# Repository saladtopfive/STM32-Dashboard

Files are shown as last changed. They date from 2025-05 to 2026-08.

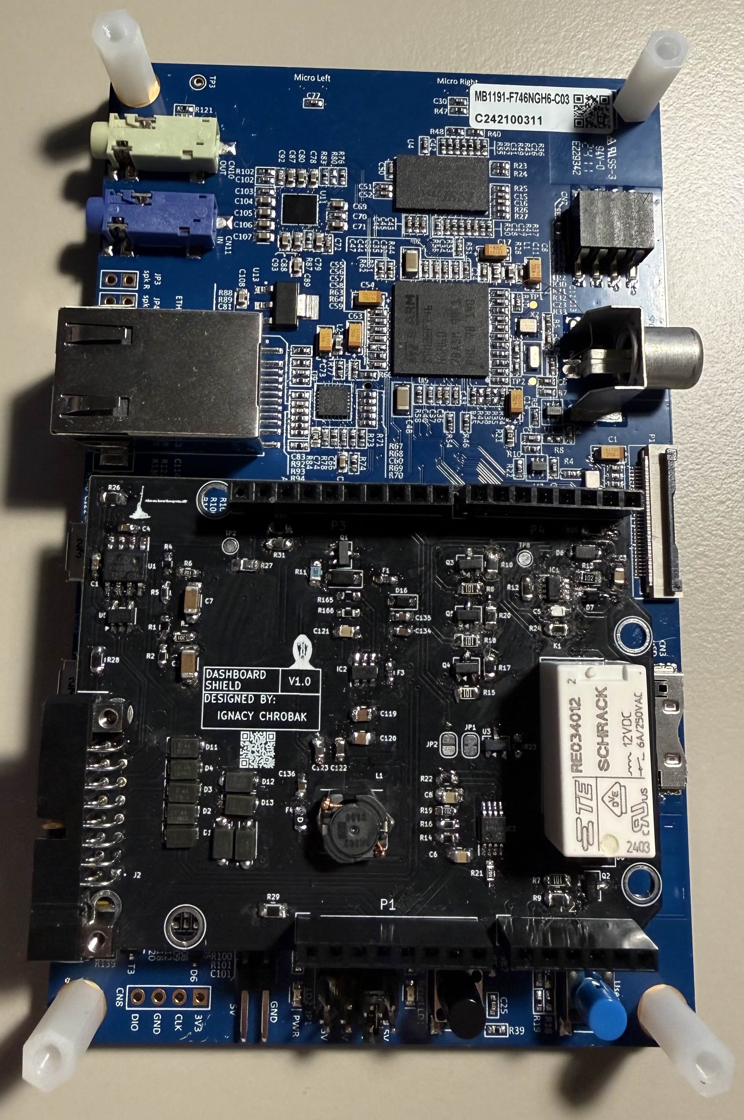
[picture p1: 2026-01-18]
readme-img/shield-stm-irl-assembly.jpg

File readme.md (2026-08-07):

# 🚘 STM32 Go-Kart Dashboard  



> [!IMPORTANT]  
> **Work suspended** — Development suspended as of **07.08.2026**  
> This repository is part of my **Engineering Thesis Project** for the completion of my undergraduate studies.  

## Overview  

This project constitutes the practical component of my **engineering thesis**, focusing on the design and implementation of a **real-time dashboard system** for an electric go-kart.  

The system is developed on the **STM32F746G-DISCO microcontroller** with a touchscreen display using **TouchGFX**, and is intended to collect, process, and visualize telemetry data from multiple hardware sensors.  

The dashboard serves as a **human–machine interface (HMI)**, enabling the driver to monitor essential parameters of the vehicle in real time. These include, but are not limited to:  

## Preview

| Main Screen | Error Table |
|---|---|
| dashboard-preview-screen1 | dashboard-preview-screen2 |

| Temperature Table | Battery Table |
|---|---|
| dashboard-preview-screen3 | dashboard-preview-screen4 |

## Monitored Metrics  

| ***Metric*** | ***Description*** |
|---|---|
| **Vehicle Speed** | Real-time speed display. |
| **Throttle / Brake** | Input level visualization. |
| **Battery** | Voltage and temperature monitoring. |
| **Motor Temperature** | Prevents overheating and ensures reliability. |
| **G-Forces** | Lateral and vertical forces in real time. |
| **BMS Data (External)** | Additional telemetry provided by an external Battery Management System (BMS), developed as a separate thesis project. This work only focuses on visualization of the received data. |
| **HOTLAP Button** | Initiates a lap timer (stopwatch) in the dashboard, showing minutes, seconds, and centiseconds. Useful for tracking lap times during testing or racing sessions. |
| **Future Extensions** | Additional sensor integrations planned. |

The objective of this work is to provide a **robust, responsive, and intuitive interface** that supports safe and efficient operation of the electric go-kart.  

## Hardware

As part of the project, a custom **Arduino Shield** is being developed to handle all sensor inputs, signal routing, and electrical interfacing between the go-kart hardware and the STM32 dashboard.  

### KiCad Schematic Preview

kicad_schematic

### KiCad 3D Model Preview

3d-render

### IRL pictures

| STM32 - dashboard | Shield |
|---|---|
| dash_realizacja_irl | shield_realizacja_irl |

## Development Notes  

The project was initially developed without version control, with the focus placed on prototyping and interface design. 

As the implementation approaches the stage of **hardware integration**, this repository has been introduced to serve as a platform for:  

- Source code management and tracking.  
- Documentation of development progress. 
- Collaboration and versioning.  

## Roadmap  

| ***Status*** | ***Task*** |
|---|---|
|  **Done** | Acquisition of the go-kart frame. |
|  **Done** | Development of the UI prototype. |
|  **Ongoing** | Live sensor data implementation. |
|  **Ongoing** | Development of an export data feature. |
|  **Ongoing** | Implementation of battery management visualization. |
|  **Planned** | Integration of BLDC motor control. |

## License
This project is licensed under the MIT permissive license.

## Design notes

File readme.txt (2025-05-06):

# STM32 Go-Kart Dashboard

A TouchGFX-based digital dashboard for a go-kart, simulating speed, throttle, G-forces, and indicators — with plans to integrate real-world sensor inputs on STM32 hardware.

---

## Overview

This project provides a real-time dashboard UI designed for STM32 microcontrollers with a touchscreen display. It visually represents speed, throttle level, G-forces (as a moving ball), and turn signals. The UI is developed using TouchGFX and STM32 HAL, currently operated through simulated hardware inputs for development on PC.

---

## Features

- **Speed display** with incremental control
- **Throttle bar** that increases while held and decays naturally
- **G-force ball** showing lateral and vertical force within a circular gauge
- **Turn indicator lights** with fade-in/fade-out flash behavior
- Dual input support: **on-screen buttons** and **hardware keys** (PC)
- Real-time **tick-based animation handling**

---

## Sensor Integration (Upcoming)

Currently, this dashboard is controlled via PC keyboard to simulate hardware inputs. The next development stage involves replacing these with real sensor data:

- Steering wheel input 
- Throttle 
- G-force 
- Turn signals 

---

## Why So Late?

The project was added to version control at a late stage because GitHub integration wasn’t deemed necessary earlier. It’s only now — approaching hardware implementation — that source tracking and documentation became essential for continued development and collaboration.

---

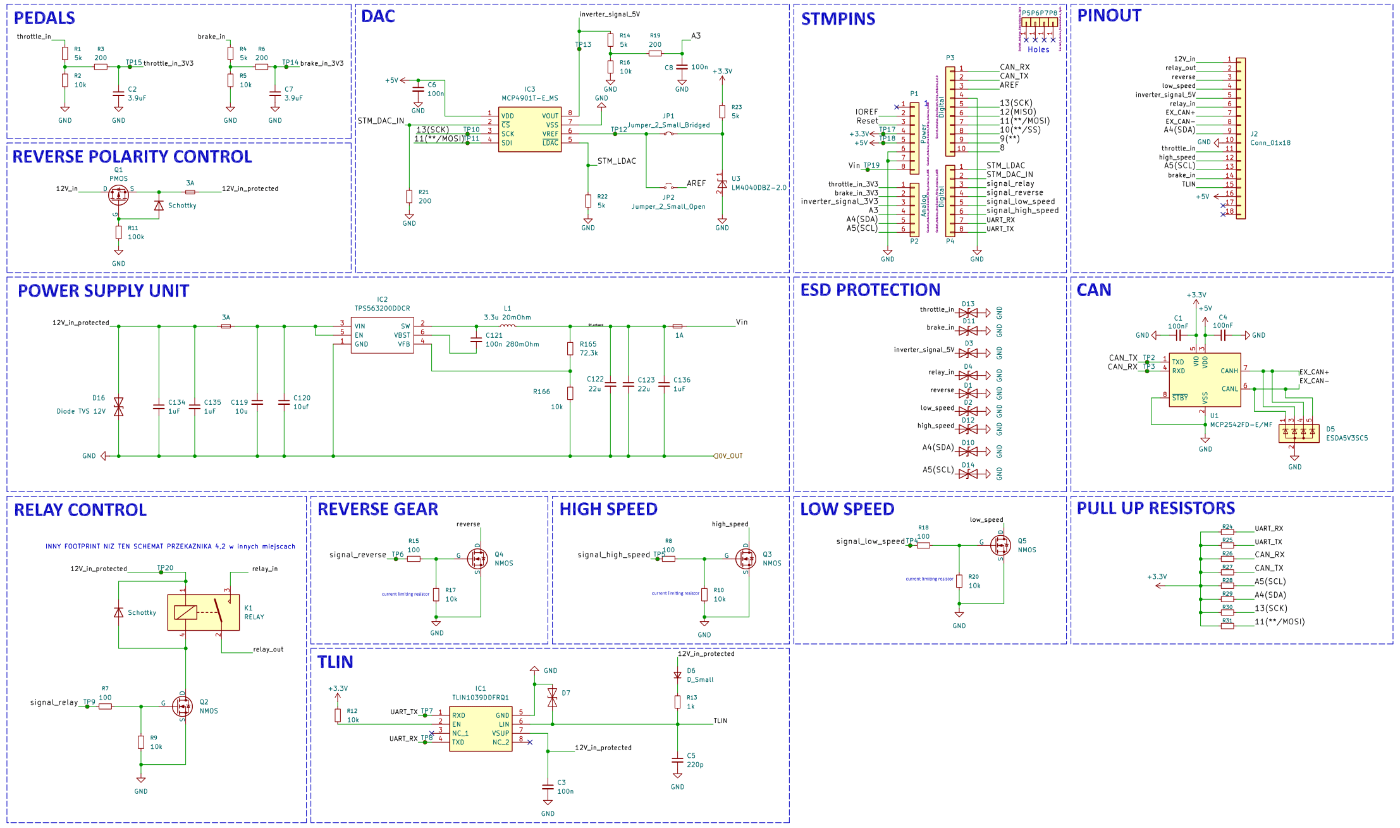
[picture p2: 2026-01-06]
readme-img/kicad_schematic.png

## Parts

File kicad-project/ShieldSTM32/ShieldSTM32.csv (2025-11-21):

Reference | Qty | Value | DNP | Exclude from BOM | Exclude from Board | Footprint | Datasheet
C1,C4 | 2 | 100nF |  |  |  | Capacitor_SMD:C_0603_1608Metric_Pad1.08x0.95mm_HandSolder | ~
C2,C7 | 2 | 3.9uF |  |  |  | Capacitor_SMD:C_1206_3216Metric_Pad1.33x1.80mm_HandSolder | https://www.mouser.pl/ProductDetail/KEMET/C1206C395M3PACTU
C3,C6,C8 | 3 | 100n |  |  |  | Capacitor_SMD:C_0805_2012Metric_Pad1.18x1.45mm_HandSolder
C5 | 1 | 220p |  |  |  | Capacitor_SMD:C_0805_2012Metric_Pad1.18x1.45mm_HandSolder
C119 | 1 | 10u |  |  |  | Capacitor_SMD:C_0805_2012Metric_Pad1.18x1.45mm_HandSolder | https://www.mouser.pl/ProductDetail/TDK/C2012X5R1V106K085AC?qs=6JAMGB%252BEdky%252BlYMcTLhFyA%3D%3D
C120 | 1 | 10uf |  |  |  | Capacitor_SMD:C_0805_2012Metric_Pad1.18x1.45mm_HandSolder | https://www.mouser.pl/ProductDetail/TDK/C2012X5R1V106K085AC?qs=6JAMGB%252BEdky%252BlYMcTLhFyA%3D%3D
C121 | 1 | 100n 280mOhm |  |  |  | Capacitor_SMD:C_0805_2012Metric_Pad1.18x1.45mm_HandSolder | https://www.mouser.pl/ProductDetail/KYOCERA-AVX/08053C104KAT2A?qs=EihRZLdKnF2GcTBzDkE%2FiQ%3D%3D
C122,C123 | 2 | 22u |  |  |  | Capacitor_SMD:C_0603_1608Metric_Pad1.08x0.95mm_HandSolder | https://www.mouser.pl/ProductDetail/TDK/C1608X5R1A226M080AC?qs=dfay7wIA1uED3Fb1o4f9Dg%3D%3D
C134,C135,C136 | 3 | 1uF |  |  |  | Capacitor_SMD:C_0603_1608Metric_Pad1.08x0.95mm_HandSolder | https://www.mouser.pl/ProductDetail/TAIYO-YUDEN/EMK107B7105MA8T
D1,D2,D3,D4,D10,D11,D12,D13,D14 | 9 | 6V |  |  |  | Diode_SMD:D_SOD-123F | https://www.mouser.pl/ProductDetail/Littelfuse/SZSMF6L6.0AT3G?qs=NeOn4crkEuuL8kPOknXE%2Fw%3D%3D
D5 | 1 | ESDA5V3SC5 |  |  |  | Package_TO_SOT_SMD:SOT-23-5 | https://www.st.com/resource/en/datasheet/esda5v3sc6.pdf
D6 | 1 | D_Small |  |  |  | footprint:SODFL3618X100N | https://www.mouser.pl/ProductDetail/Comchip-Technology/ACGRTS4002-HF?qs=vLWxofP3U2xDO8WfdetXSg%3D%3D
D7 | 1 | ESD131-B1-W0201 |  |  |  | footprint:SOD2613X100N | https://www.mouser.pl/ProductDetail/Texas-Instruments/ESD1LIN24DYFR?qs=rQFj71Wb1eUZk7C7kdpseg%3D%3D
D8,D9 | 2 | Schottky |  |  |  | Diode_SMD:D_SOD-123 | https://www.mouser.pl/ProductDetail/Taiwan-Semiconductor/SD103BWH-RHG?qs=jcD%2FCkGBYeNNhWZ4uMM1kw%3D%3D
D16 | 1 | Diode TVS 12V |  |  |  | Diode_SMD:D_SOD-323_HandSoldering | https://www.mouser.pl/ProductDetail/Diodes-Incorporated/SD12C-7?qs=EBDBlbfErPxugjAb5VaoMA%3D%3D
F1,F3 | 2 | 3A |  |  |  | Fuse:Fuse_0603_1608Metric_Pad1.05x0.95mm_HandSolder | https://www.mouser.pl/ProductDetail/Bourns/SF-0603FP300F-2?qs=55YtniHzbhAz28pQ%252B5v2Gg%3D%3D
F4 | 1 | 1A |  |  |  | Fuse:Fuse_0603_1608Metric_Pad1.05x0.95mm_HandSolder | https://www.mouser.pl/ProductDetail/Bourns/SF-0603F100-2
IC1 | 1 | TLIN1039DDFRQ1 |  |  |  | SOT65P280X110-8N | https://www.ti.com/product/TLIN1039-Q1
IC2 | 1 | TPS563200DDCR |  |  |  | footprint:TPS563200DDCR | http://www.ti.com/lit/gpn/TPS563200
IC3 | 1 | MCP4901T-E_MS |  |  |  | SOP65P490X110-8N | https://datasheet.datasheetarchive.com/originals/dk/DKDS41/DSANUWW0026513.pdf
J2 | 1 | Conn_01x18 |  |  |  | footprint:M80-54016YY | https://www.mouser.pl/ProductDetail/Harwin/M80-5401642?qs=wuXwK9wHm9sx2x5KnF4SHQ%3D%3D
JP1 | 1 | Jumper_2_Small_Bridged |  |  |  | Jumper:SolderJumper-2_P1.3mm_Bridged_RoundedPad1.0x1.5mm | ~
JP2 | 1 | Jumper_2_Small_Open |  |  |  | Jumper:SolderJumper-2_P1.3mm_Open_RoundedPad1.0x1.5mm | ~
K1 | 1 | RELAY |  |  |  | footprint:RE034012 | https://www.mouser.pl/ProductDetail/TE-Connectivity/RE034012?qs=9VCAlN3zIjnPkD8RaiRpIA%3D%3D
L1 | 1 | 3.3u 20mOhm |  |  |  | footprint:CLF7045__ | https://www.mouser.pl/ProductDetail/TDK/CLF7045NIT-3R3N-D?qs=P8zzrVhehaveWwbrqo7%252Bdg%3D%3D
P1 | 1 | Power |  |  |  | Socket_Arduino_Uno:Socket_Strip_Arduino_1x08
P2 | 1 | Analog |  |  |  | Socket_Arduino_Uno:Socket_Strip_Arduino_1x06
P3 | 1 | Digital |  |  |  | Socket_Arduino_Uno:Socket_Strip_Arduino_1x10
P4 | 1 | Digital |  |  |  | Socket_Arduino_Uno:Socket_Strip_Arduino_1x08
P5,P6,P7,P8 | 4 | CONN_01X01 |  |  |  | Socket_Arduino_Uno:Arduino_1pin
Q1 | 1 | PMOS |  |  |  | Package_TO_SOT_SMD:SOT-23-3 | https://www.mouser.pl/ProductDetail/onsemi/NTR4502PT1G?qs=ZXBb0xZ9WeB%2Fr7xn7qkqLg%3D%3D
Q2,Q3,Q4,Q5 | 4 | NMOS |  |  |  | Package_TO_SOT_SMD:SOT-23-3 | https://www.mouser.pl/ProductDetail/onsemi/NTR4003NT3G?qs=CBDP9nzV7kn2N6bgfQxrAA%3D%3D
R1,R4,R14,R22,R23 | 5 | 5k |  |  |  | Resistor_SMD:R_0603_1608Metric_Pad0.98x0.95mm_HandSolder | ~
R2,R5,R16 | 3 | 10k |  |  |  | Resistor_SMD:R_0603_1608Metric_Pad0.98x0.95mm_HandSolder | ~
R3,R6,R19,R21 | 4 | 200 |  |  |  | Resistor_SMD:R_0603_1608Metric_Pad0.98x0.95mm_HandSolder | ~
R7,R8,R15,R18 | 4 | 100 |  |  |  | Resistor_SMD:R_0805_2012Metric_Pad1.20x1.40mm_HandSolder | ~
R9,R10,R12,R17,R20,R24,R25,R26,R27,R28,R29,R30,R31 | 13 | 10k |  |  |  | Resistor_SMD:R_0805_2012Metric_Pad1.20x1.40mm_HandSolder | ~
R11 | 1 | 100k |  |  |  | Resistor_SMD:R_0805_2012Metric_Pad1.20x1.40mm_HandSolder | ~
R13 | 1 | 1k |  |  |  | Resistor_SMD:R_0805_2012Metric_Pad1.20x1.40mm_HandSolder | ~
R165 | 1 | 56.2k 50mW |  |  |  | Resistor_SMD:R_0603_1608Metric_Pad0.98x0.95mm_HandSolder | https://www.mouser.pl/ProductDetail/YAGEO/RC0201FR-0756K2L?qs=Q4gDqC5t5%2FD3%2Fkjmz2Nr%2Fw%3D%3D
R166 | 1 | 10k 50mW |  |  |  | Resistor_SMD:R_0603_1608Metric_Pad0.98x0.95mm_HandSolder | ~
TP2,TP3,TP4,TP5,TP6,TP7,TP8,TP9,TP10,TP11,TP12,TP13,TP14,TP15,TP17,TP18,TP19,TP20 | 18 | TestPoint_Small |  |  |  | TestPoint:TestPoint_Pad_D1.5mm | ~
U1 | 1 | MCP2542FD-E/MF |  |  |  | footprint:SOIC127P600X175-8N | https://www.mouser.pl/ProductDetail/Microchip-Technology/MCP2542FD-E-SN?qs=qdgZG5p0FZ5pNizBl1u80Q%3D%3D
U3 | 1 | LM4040DBZ-2.0 |  |  |  | Package_TO_SOT_SMD:SOT-23 | http://www.ti.com/lit/ds/symlink/lm4040-n.pdf

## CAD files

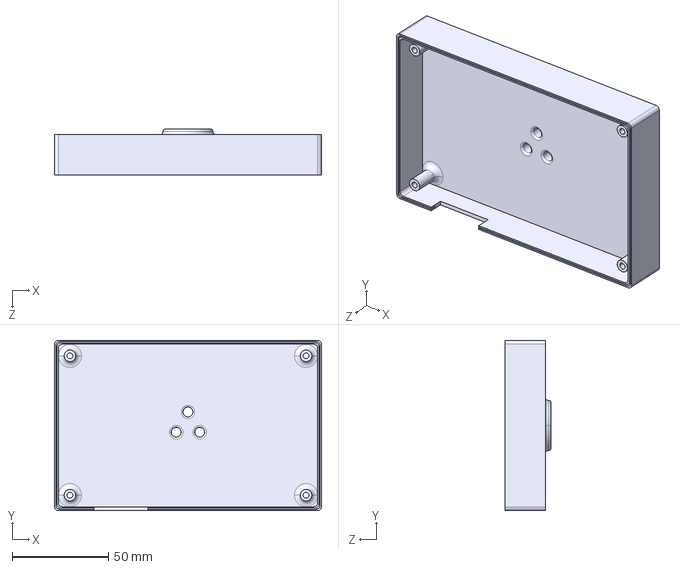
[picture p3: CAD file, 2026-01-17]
freecad-project-mounting_plate/dash_mounting-3dmodel/tyl.STEP
138.4 x 88.2 x 24.0 mm

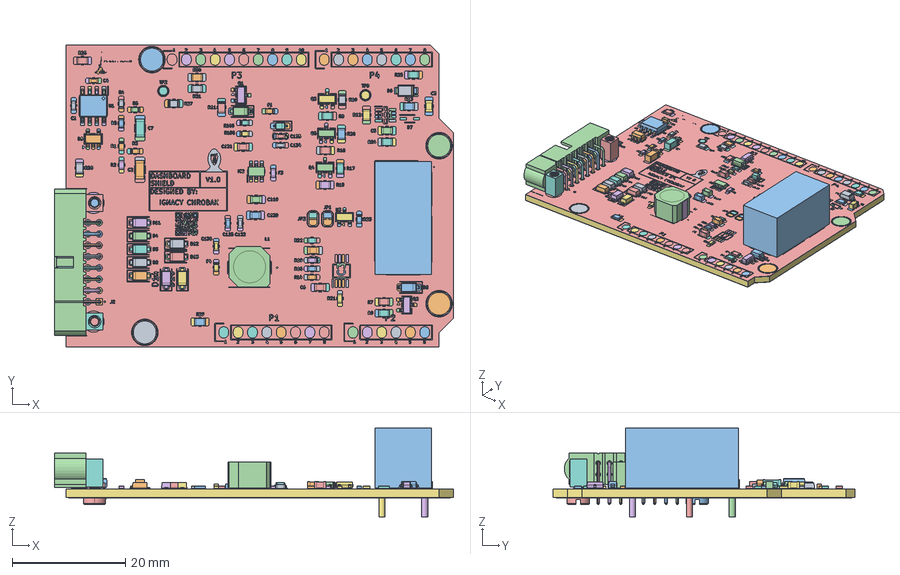
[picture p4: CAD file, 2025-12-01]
freecad-project-mounting_plate/shield-3dmodel/3dmodel.FCStd
70.6 x 53.3 x 15.7 mm
R_0805_2012Metric
C_0603_1608Metric
PinsArrayLR
PinsArrayLR001
PinsArrayLR002
PinsArrayLR003
PinsArrayLR004
PinsArrayLR005
PinsArrayLR006
PinsArrayLR007
BODY-SOT
LEAD-SOT
LEAD-SOT001
LEAD-SOT002
LEAD-SOT003
LEAD-SOT004
LEAD-SOT005
R_0805_2012Metric001
D_SOD-123
D_SOD-123F
D_SOD-123F001
Fuse_0603_1608Metric
D_SOD-323
C_0603_1608Metric001
D_SOD-123F002
C_0603_1608Metric002
R_0603_1608Metric
C_0805_2012Metric
R_0603_1608Metric001
R_0805_2012Metric002
D_SOD-123F003
PinKIdent
PinK
PinA
R_0805_2012Metric003
SOT-23-3
C_0603_1608Metric003
R_0603_1608Metric002
C_0603_1608Metric004
R_0603_1608Metric003
R_0805_2012Metric004
SOT-23-004
R_0805_2012Metric005
R_0805_2012Metric006
R_0603_1608Metric004
R_0603_1608Metric005
R_0805_2012Metric007
Fuse_0603_1608Metric001
R_0805_2012Metric008
C_0805_2012Metric001
C_0805_2012Metric002
Fuse_0603_1608Metric002
C_0805_2012Metric003
R_0805_2012Metric009
R_0805_2012Metric010
C_1206_3216Metric
R_0603_1608Metric006
C_0805_2012Metric004
R_0805_2012Metric011
R_0603_1608Metric007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

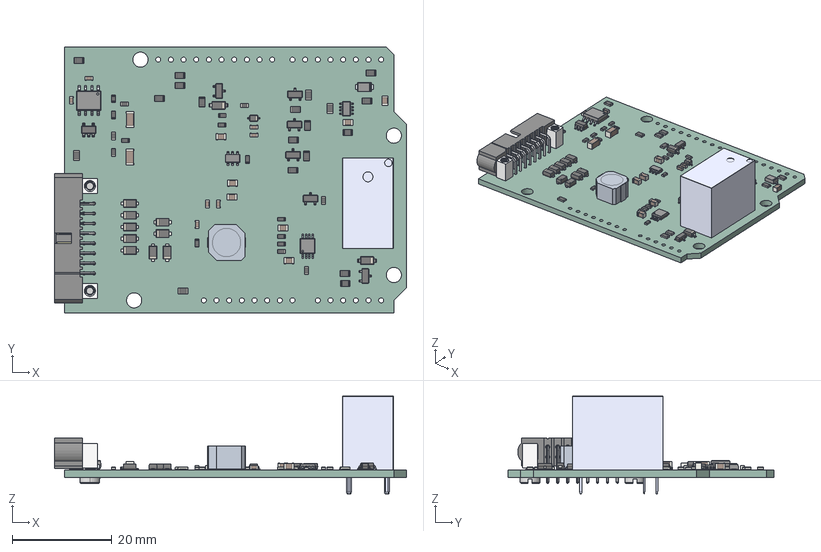
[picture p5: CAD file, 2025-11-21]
kicad-project/project/step/ShieldArduino_Semaforo.step
70.6 x 53.3 x 19.6 mm
Socket_header_Arduino_1x08 x 2
Socket_header_Arduino_1x06
Socket_header_Arduino_1x10
R_0805_2012Metric x 19
C_0603_1608Metric x 7
PinsArrayLR x 2
BODY-SOT
LEAD-SOT x 6
D_SOD-123 x 2
D_SOD-123F x 9
Fuse_0603_1608Metric x 3
D_SOD-323
R_0603_1608Metric x 14
C_0805_2012Metric x 7
PinKIdent
PinK
PinA
SOT-23-3 x 5
BODY-SO
LEAD-SO x 8
PIN1-ID
C_1206_3216Metric x 2
CLF7045NIf
CLF7045NI[q x 2
PR4-12V-450-1A
M80-2702098_SEPARATE_ROWS
M80-530XX22_SHORT_PIN x 8
M80-530XX22_LONG_PIN x 8
SOT-23-5
SOT-23
ShieldArduino_Semaforo_PCB

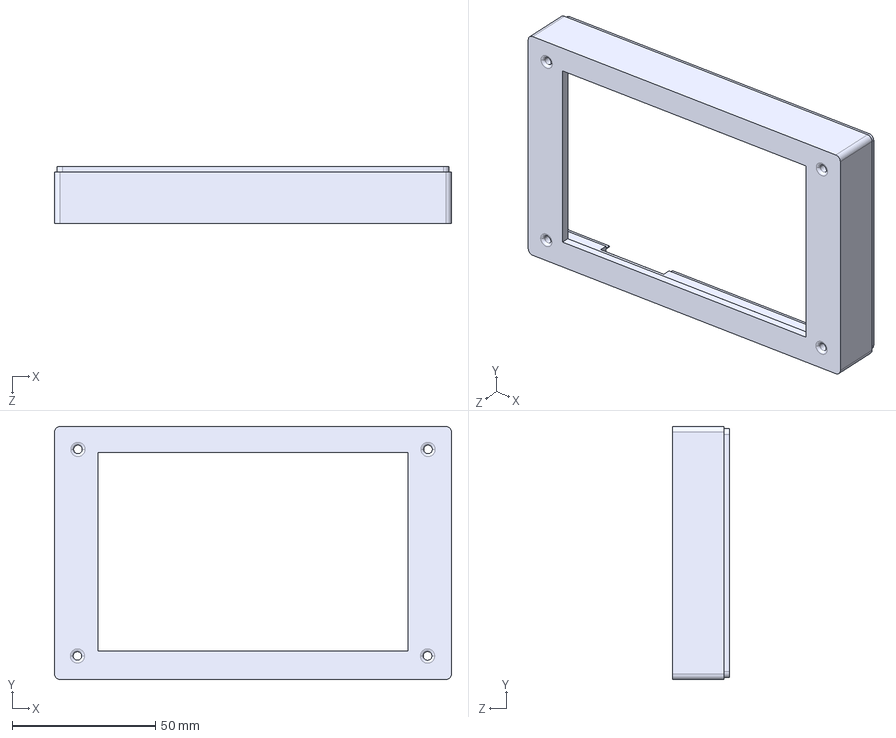
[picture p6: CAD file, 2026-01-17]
freecad-project-mounting_plate/dash_mounting-3dmodel/przod.STEP
138.4 x 88.2 x 20.0 mm

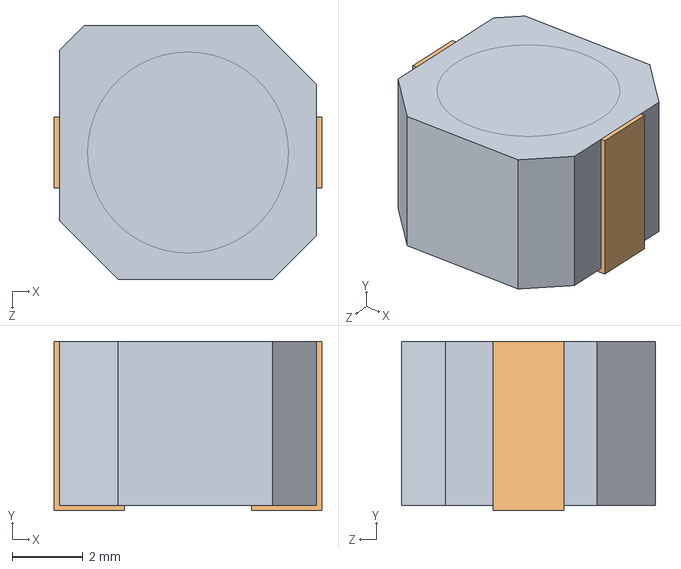
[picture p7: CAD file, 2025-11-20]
kicad-project/ShieldSTM32/include/model/CLF7045NIT-3R3N-D.stp
7.60 x 4.80 x 7.20 mm
CLF7045NI素体
CLF7045NI端子 x 2

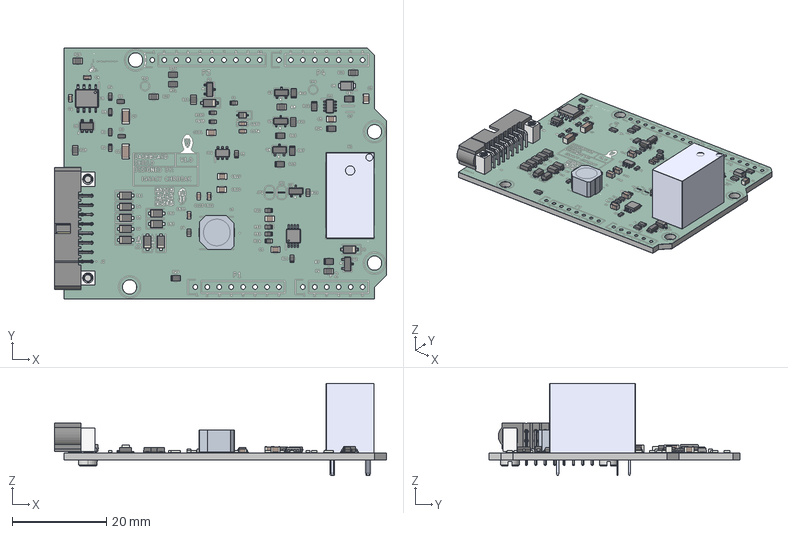
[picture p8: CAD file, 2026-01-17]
freecad-project-mounting_plate/dash_mounting-3dmodel/ShieldArduino_Semaforo.step
70.6 x 53.3 x 19.6 mm
Socket_header_Arduino_1x08 x 2
Socket_header_Arduino_1x06
Socket_header_Arduino_1x10
R_0805_2012Metric x 19
C_0603_1608Metric x 7
PinsArrayLR x 2
BODY-SOT
LEAD-SOT x 6
D_SOD-123 x 2
D_SOD-123F x 9
Fuse_0603_1608Metric x 3
D_SOD-323
R_0603_1608Metric x 14
C_0805_2012Metric x 7
PinKIdent
PinK
PinA
SOT-23-3 x 5
BODY-SO
LEAD-SO x 8
PIN1-ID
C_1206_3216Metric x 2
CLF7045NIf
CLF7045NI[q x 2
PR4-12V-450-1A
M80-2702098_SEPARATE_ROWS
M80-530XX22_SHORT_PIN x 8
M80-530XX22_LONG_PIN x 8
SOT-23-5
SOT-23
ShieldArduino_Semaforo_silkscreen
ShieldArduino_Semaforo_soldermask
ShieldArduino_Semaforo_PCB

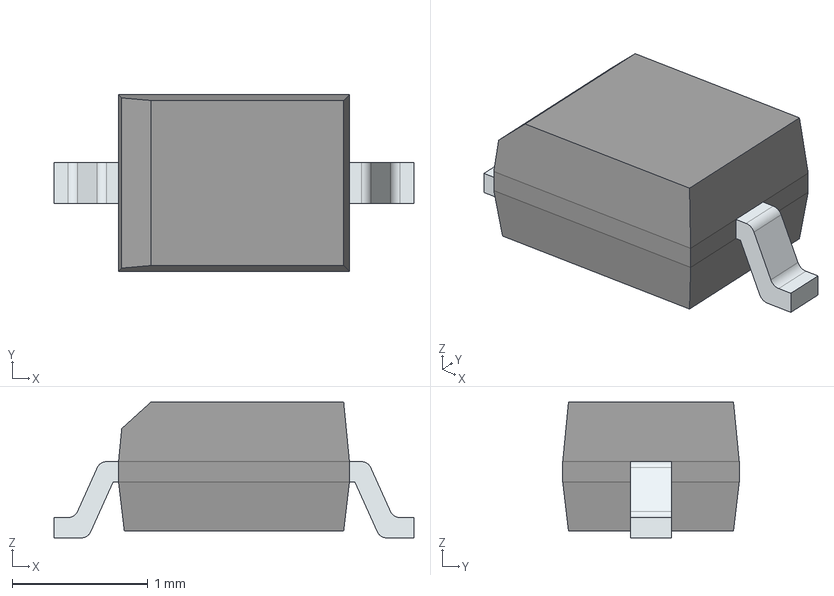
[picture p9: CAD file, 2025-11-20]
kicad-project/ShieldSTM32/include/model/ESD1LIN24DYFR.stp
2.65 x 1.30 x 1.00 mm
FilletPinL
FilletPinR

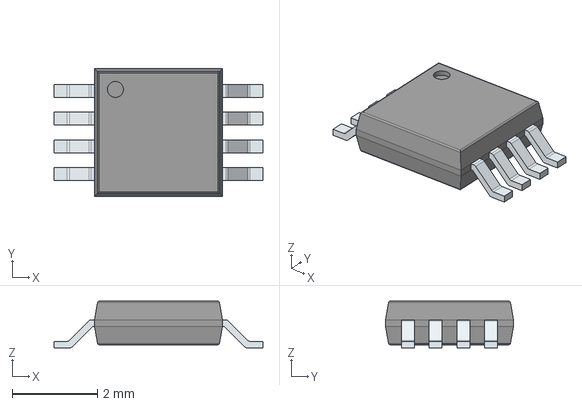
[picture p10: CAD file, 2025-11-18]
kicad-project/ShieldSTM32/include/model/MCP4901T-E_MS.stp
4.90 x 3.00 x 1.10 mm
PinsArrayLR

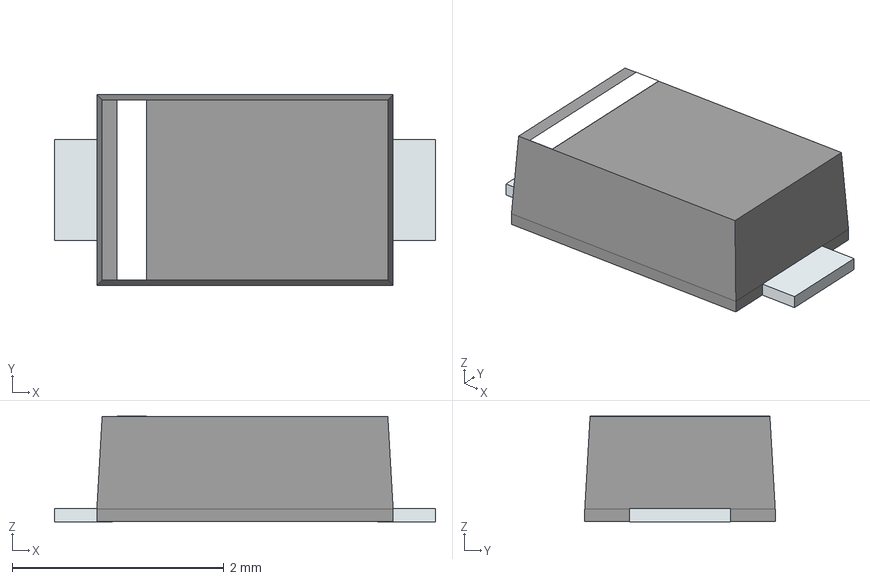
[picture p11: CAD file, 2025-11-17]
kicad-project/ShieldSTM32/include/model/ACGRTS4002-HF.stp
3.60 x 1.80 x 1.00 mm
PinKIdent
PinK
PinA

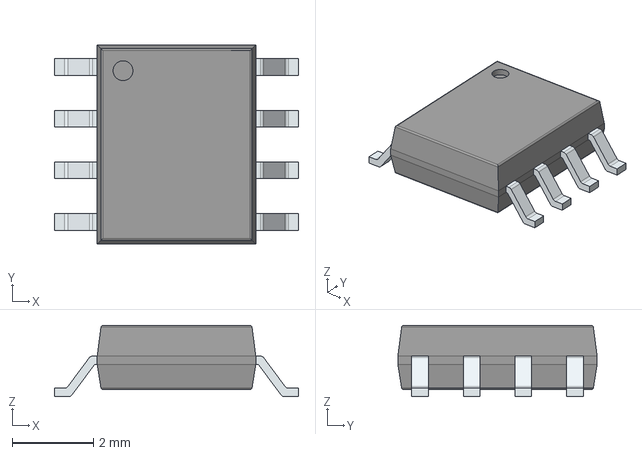
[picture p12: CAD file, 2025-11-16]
kicad-project/ShieldSTM32/include/model/MCP2542FD-E_SN.stp
6.00 x 4.90 x 1.75 mm
PinsArrayLR

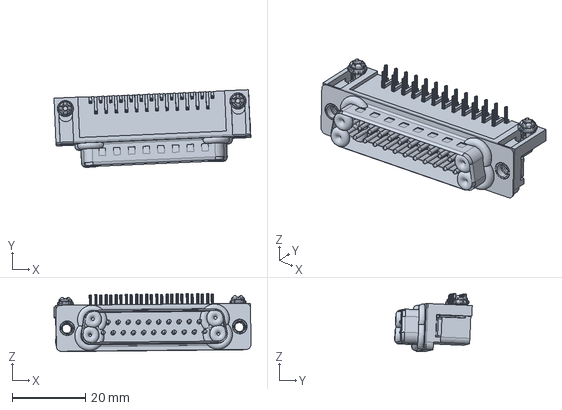
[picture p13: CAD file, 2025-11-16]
kicad-project/ShieldSTM32/include/model/L717SDB25PA4CH3R.stp
53.6 x 21.1 x 15.8 mm

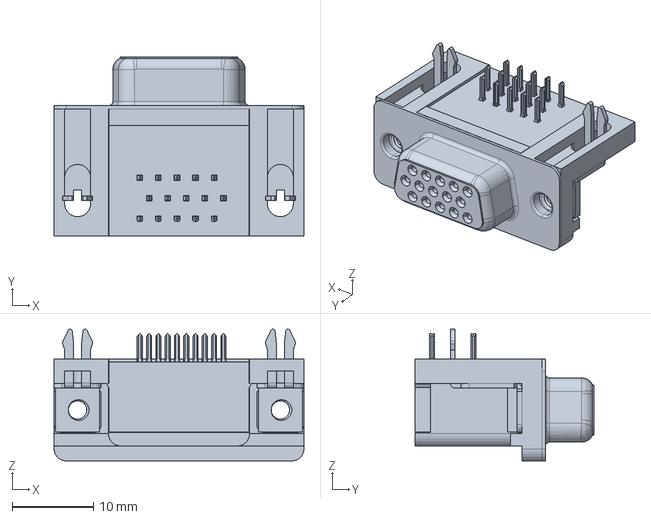
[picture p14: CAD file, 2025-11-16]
kicad-project/ShieldSTM32/include/model/L17HTHES4R1C.stp
30.8 x 22.1 x 16.2 mm

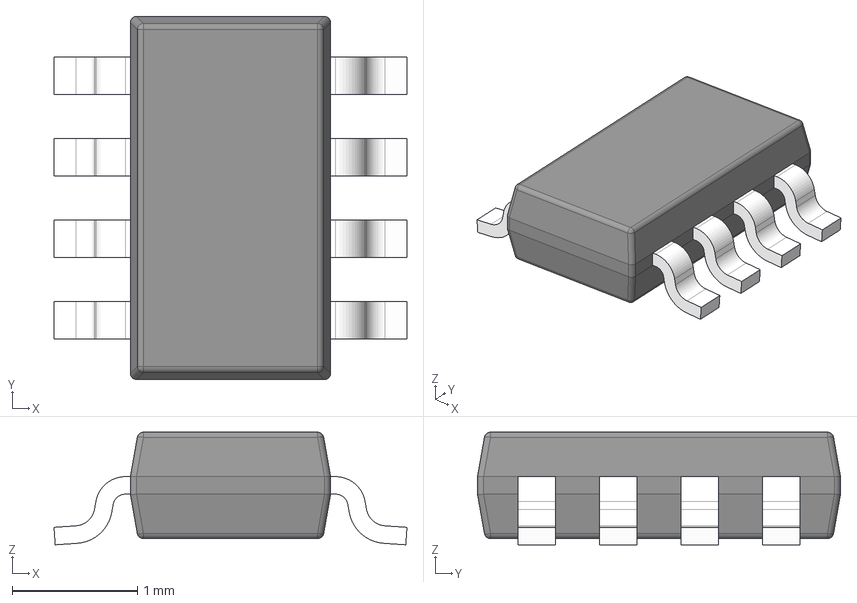
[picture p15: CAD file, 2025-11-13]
kicad-project/ShieldSTM32/include/model/TLIN1039DDFRQ1.stp
2.82 x 2.90 x 0.9 mm
BODY-SO
LEAD-SO x 8
PIN1-ID

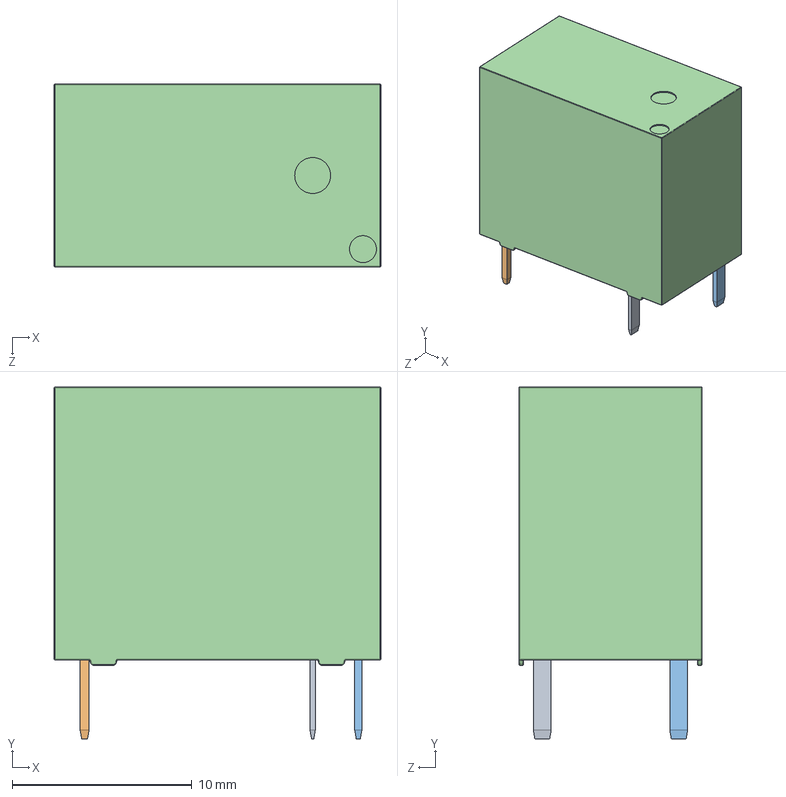
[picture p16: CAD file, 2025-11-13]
kicad-project/ShieldSTM32/include/model/PR4-12V-450-1A.stp
18.2 x 19.6 x 10.2 mm

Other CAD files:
freecad-project-mounting_plate/dash_mounting-3dmodel/dash.SLDASM
kicad-project/ShieldSTM32/include/model/M80-5001042.stp
kicad-project/ShieldSTM32/include/model/RE034012.stp
kicad-project/ShieldSTM32/include/model/M80-5401642.stp
freecad-project-mounting_plate/dash_mounting-3dmodel/przod.SLDPRT
freecad-project-mounting_plate/dash_mounting-3dmodel/tyl.SLDPRT
kicad-project/ShieldSTM32/include/model/TPS54302DDCR.stp

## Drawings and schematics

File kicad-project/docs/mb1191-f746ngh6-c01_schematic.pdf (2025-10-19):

Title: Project overview

Size:

Reference:
A4 | Sheet: | of

Revision:

Project: STM32F746G-DISCO

C 01 | MB1191

F746NGH6

Date:

Variant:

Table of contents | Legend

General comment such as function title, configuration, ...

Text to be added to silkscreen.

# STM32F746G-DISCO

MB1191

Warning text.

# Open Platform License Agreement

The Open Platform License Agreement (“Agreement”) is a binding legal contract between you ("You")

and STMicroelectronics International N.V. (“ST”), a company incorporated under the laws of the

Netherlands acting for the purpose of this Agreement through its Swiss branch 39, Chemin du

Champ des Filles, 1228 Plan-les-Ouates, Geneva, Switzerland.

By using the enclosed reference designs, schematics, PC board layouts, and documentation, in hardcopy

or CAD tool file format (collectively, the “Reference Material”), You are agreeing to be bound by

the terms and conditions of this Agreement. Do not use the Reference Material until You have read

and agreed to this Agreement terms and conditions. The use of the Reference Material automatically

implies the acceptance of the Agreement terms and conditions.

The complete Open Platform License Agreement can be found on www.st.com/opla.

U_Top
Top.SchDoc

Sheet 1: Project overview (this page)

Sheet 2: Top

Sheet 4: ST-LINK/V2-1 with support of SWD only

Sheet 5: Joystick, ACP, LEDs and Push Button

Sheet 8: Arduino UNO connectors

Sheet 10: USB OTG FS with Micro A-B connector

Sheet 7: Quad SPI Flash Memory (MICRON)

Sheet 6: Audio Codec WOLFSON and connectors

Sheet 9: SDRAM (MICRON)

Sheet 3: STM32F746NGH6 Connexion

Sheet 11: USB OTG HS PHY with Micro A-B connector

Sheet 12: Ethernet PHY with RJ45 connector

Sheet 13: External Camera connector

Sheet 14: LCD 4.3" with Capacitive Touch

Notes to generate the
board layout.

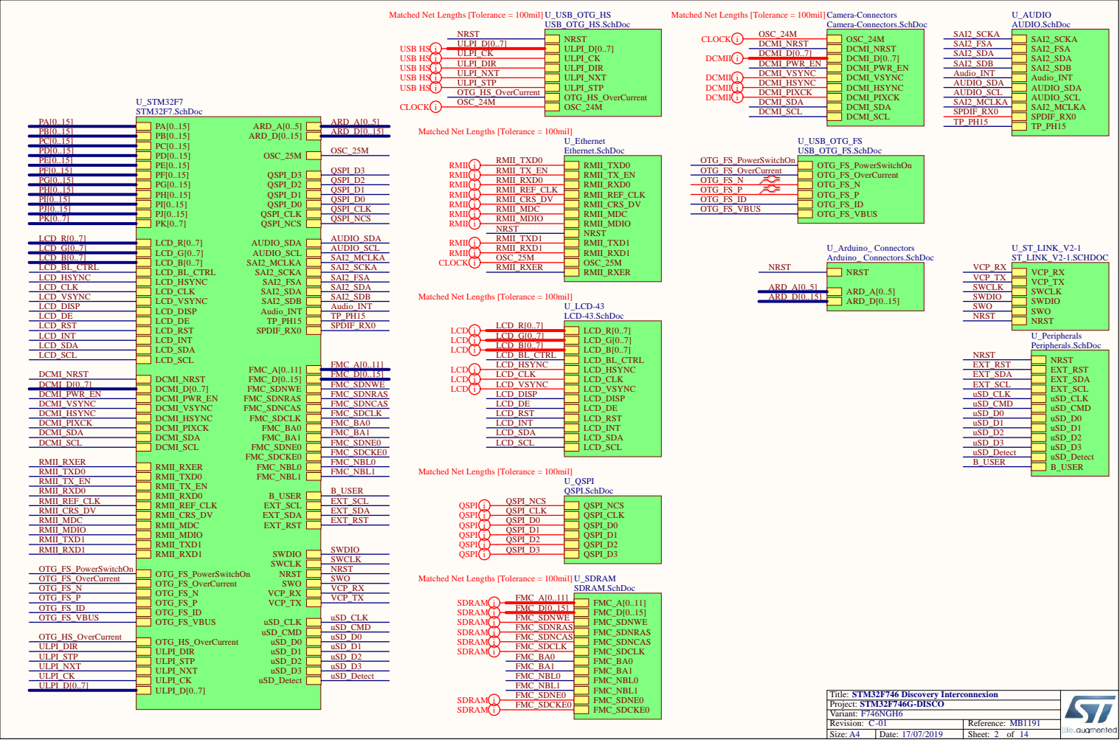
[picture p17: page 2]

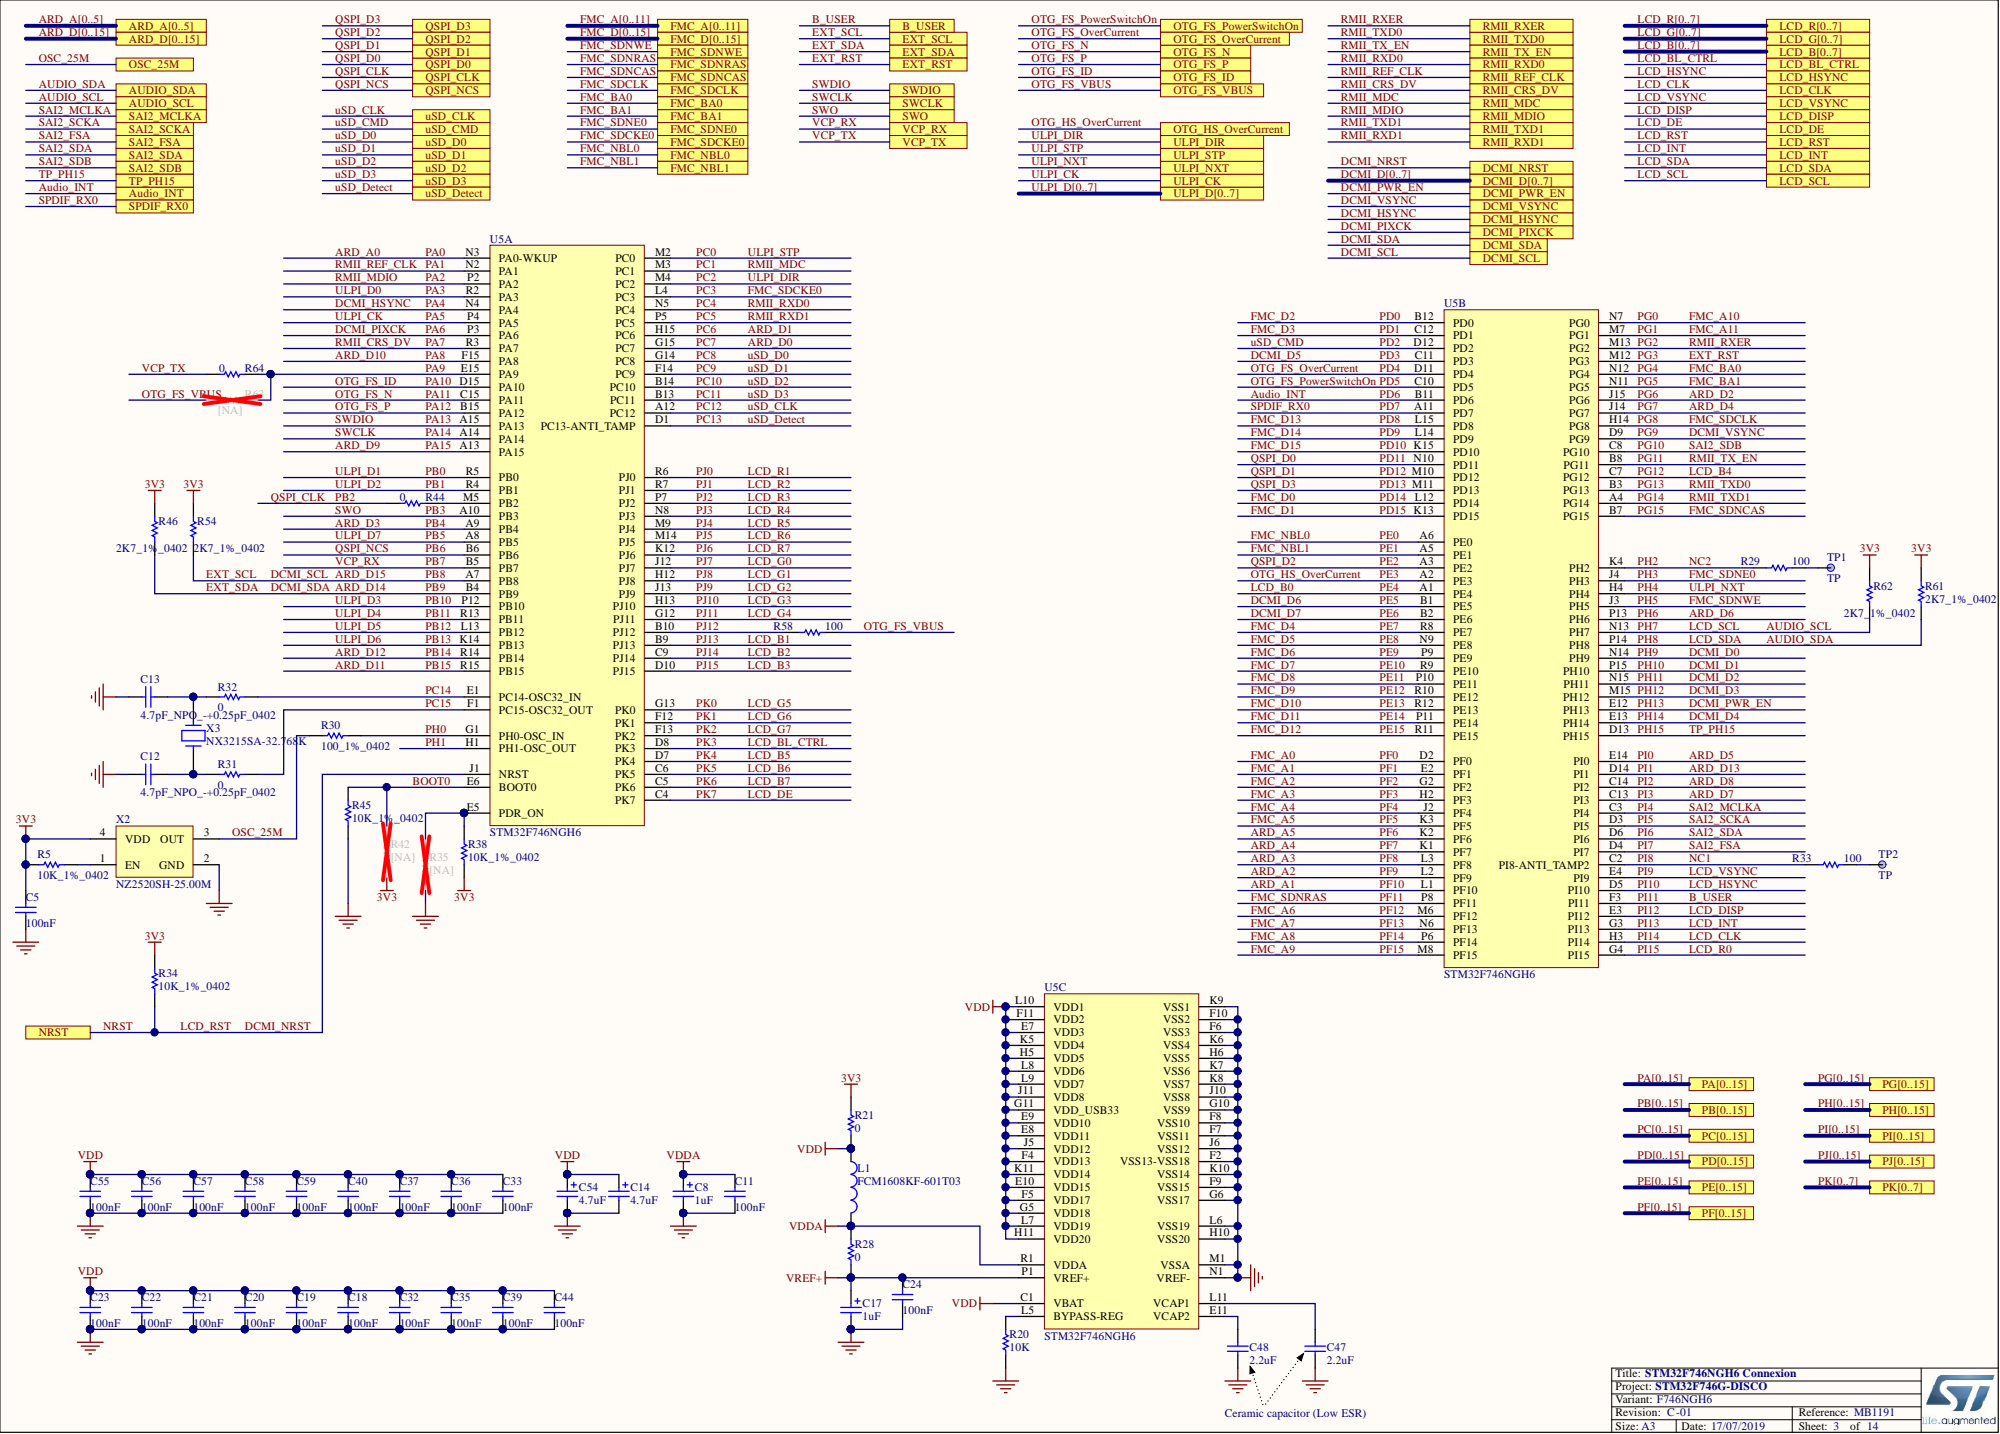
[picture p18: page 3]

VREF+ P1

Ceramic capacitor (Low ESR)

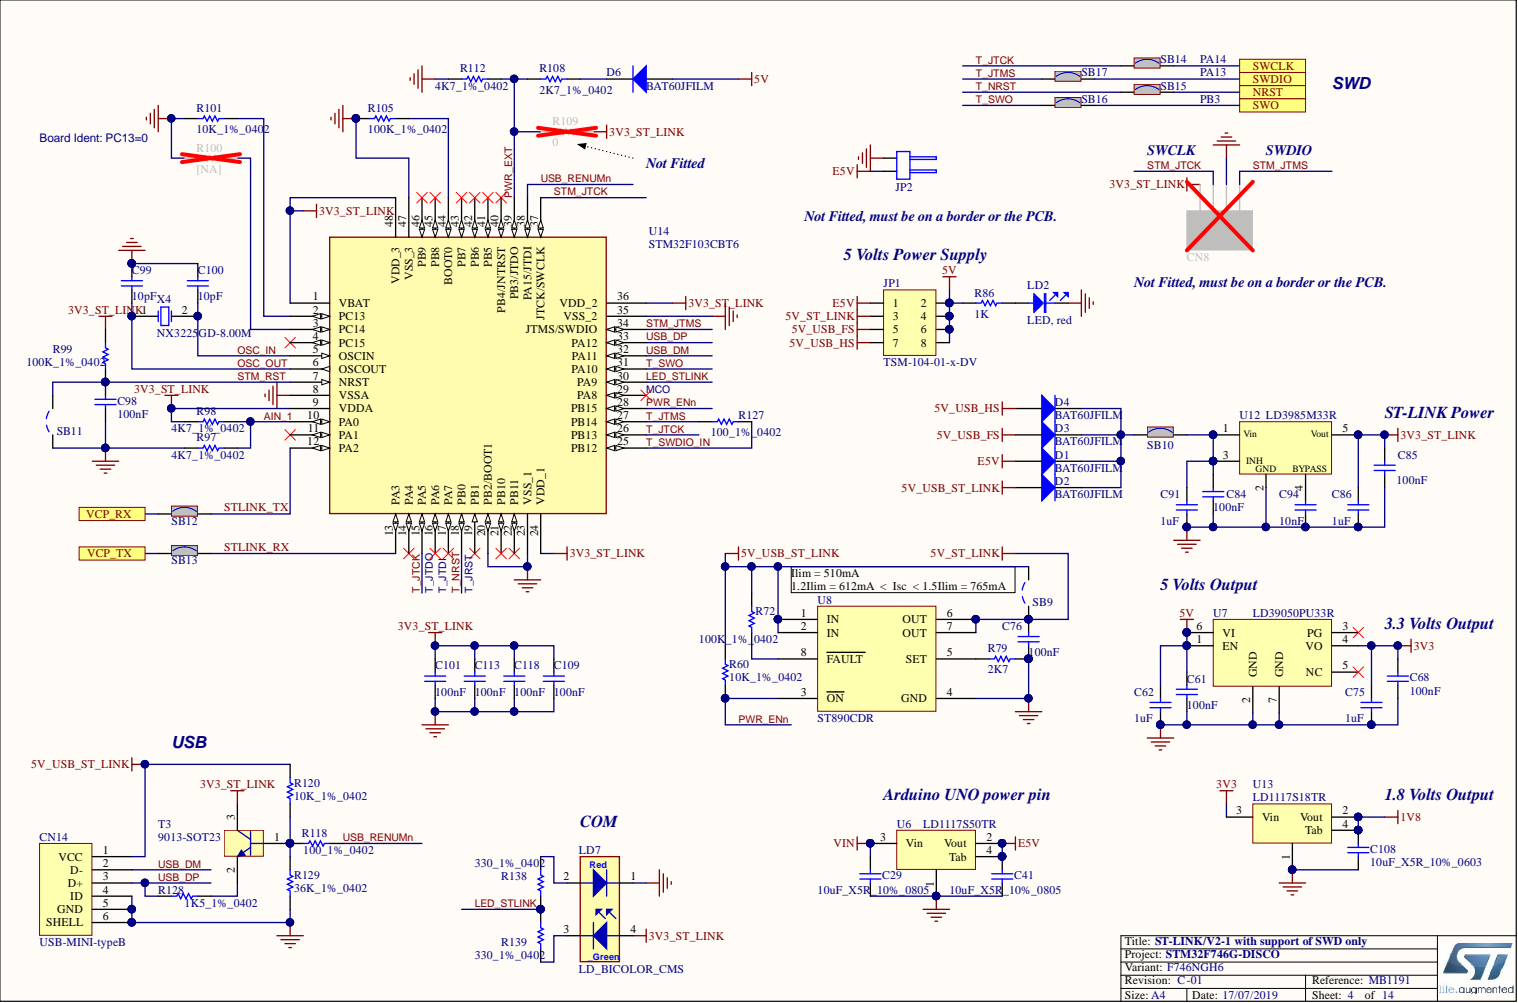
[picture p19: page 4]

Not Fitted, must be on a border or the PCB.

Arduino UNO power pin

Title: ST-LINK/V2-1 with support of SWD only

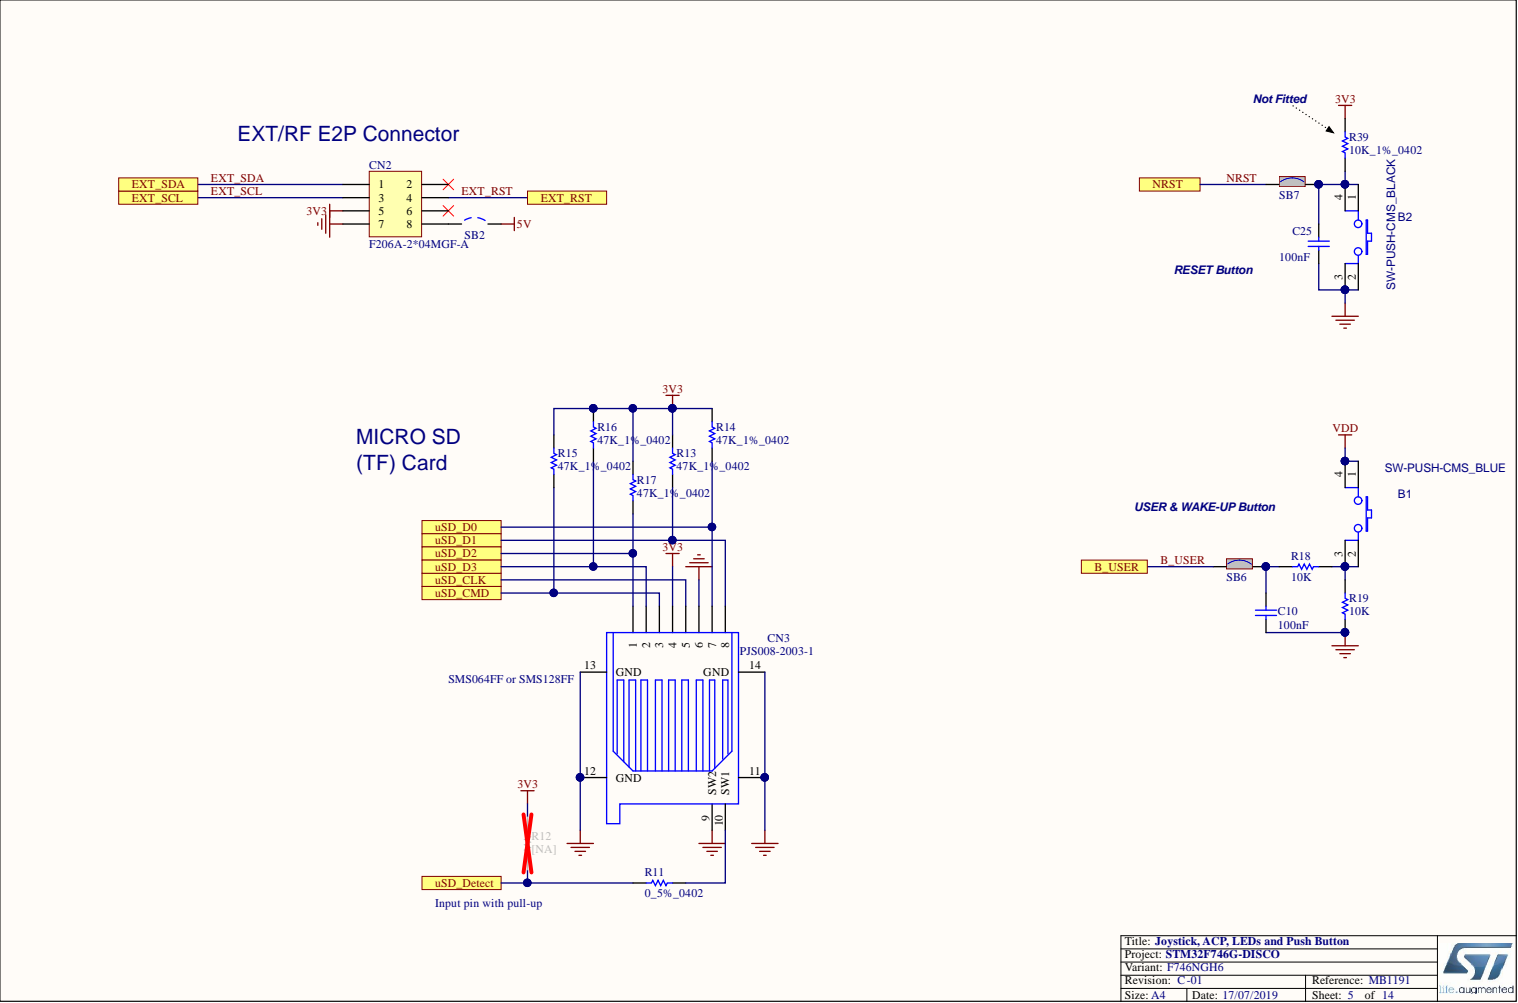
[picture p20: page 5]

USER & WAKE-UP Button

uSD_Detect
Input pin with pull-up

Title: Joystick, ACP, LEDs and Push Button

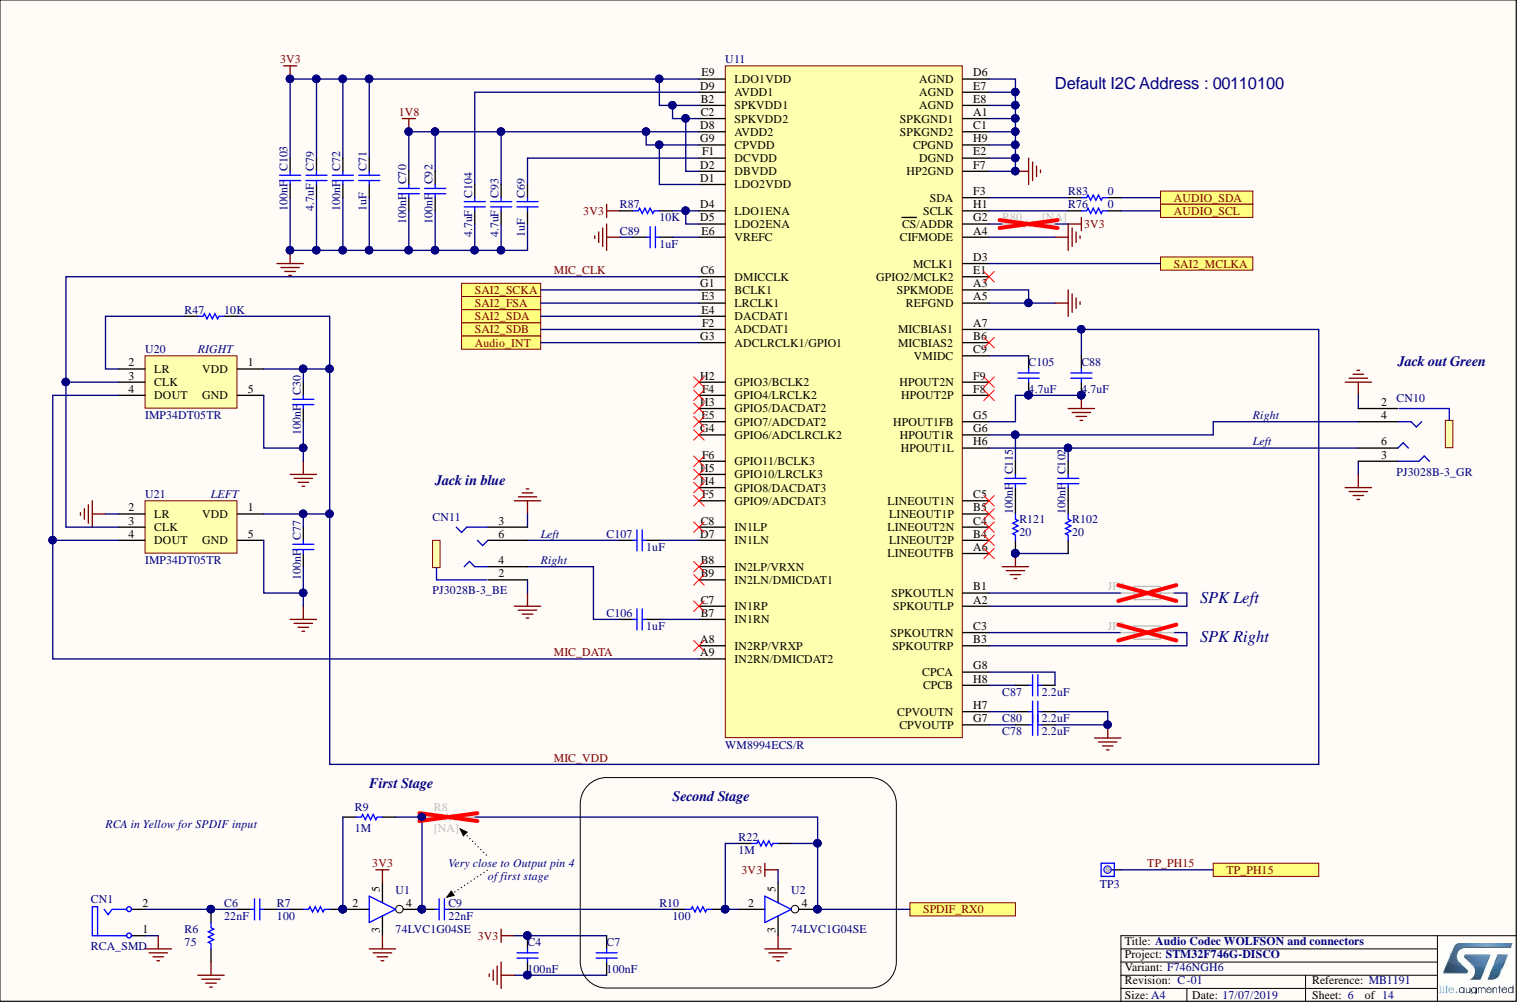
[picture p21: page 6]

AVDD1 D9
SPKVDD1 B2
SPKVDD2 C2
AVDD2 D8
CPVDD G9
DCVDD F1

BCLK1 G1
LRCLK1 E3
DACDAT1 E4
ADCDAT1 F2

CLK 3 LR 2

GPIO4/LRCLK2 F4

RCA in Yellow for SPDIF input

Very close to Output pin 4

Title: Audio Codec WOLFSON and connectors

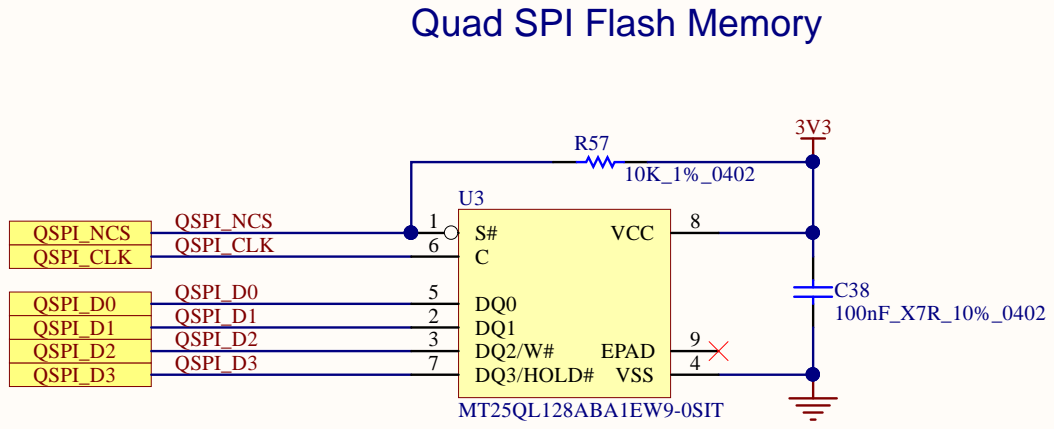
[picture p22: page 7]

Quad SPI Flash Memory

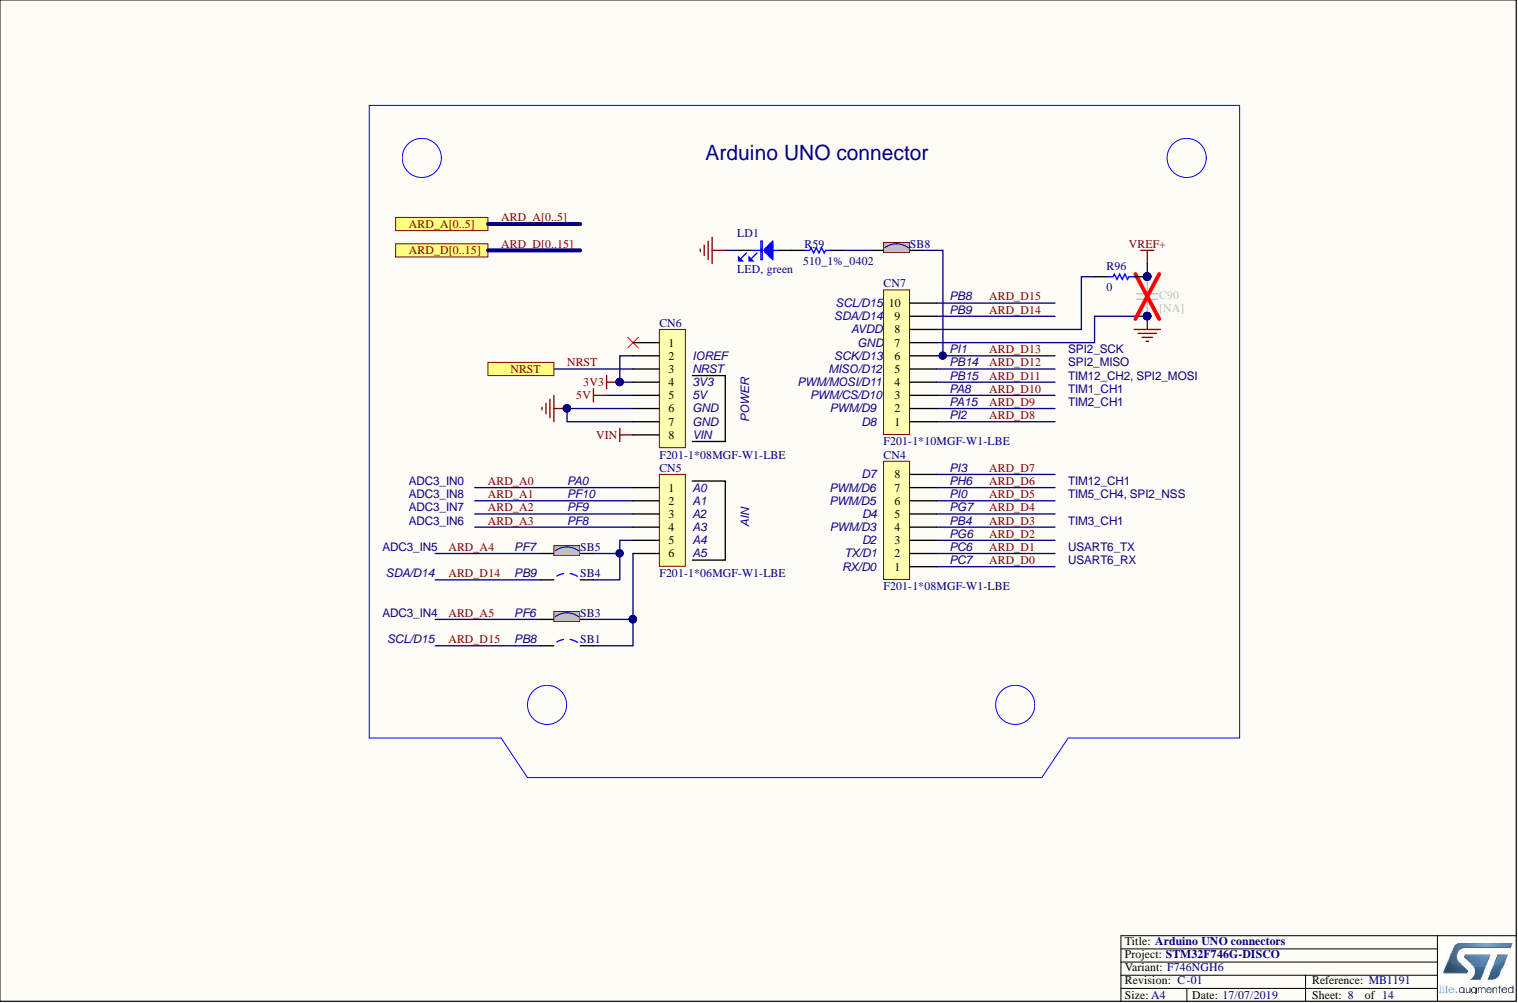
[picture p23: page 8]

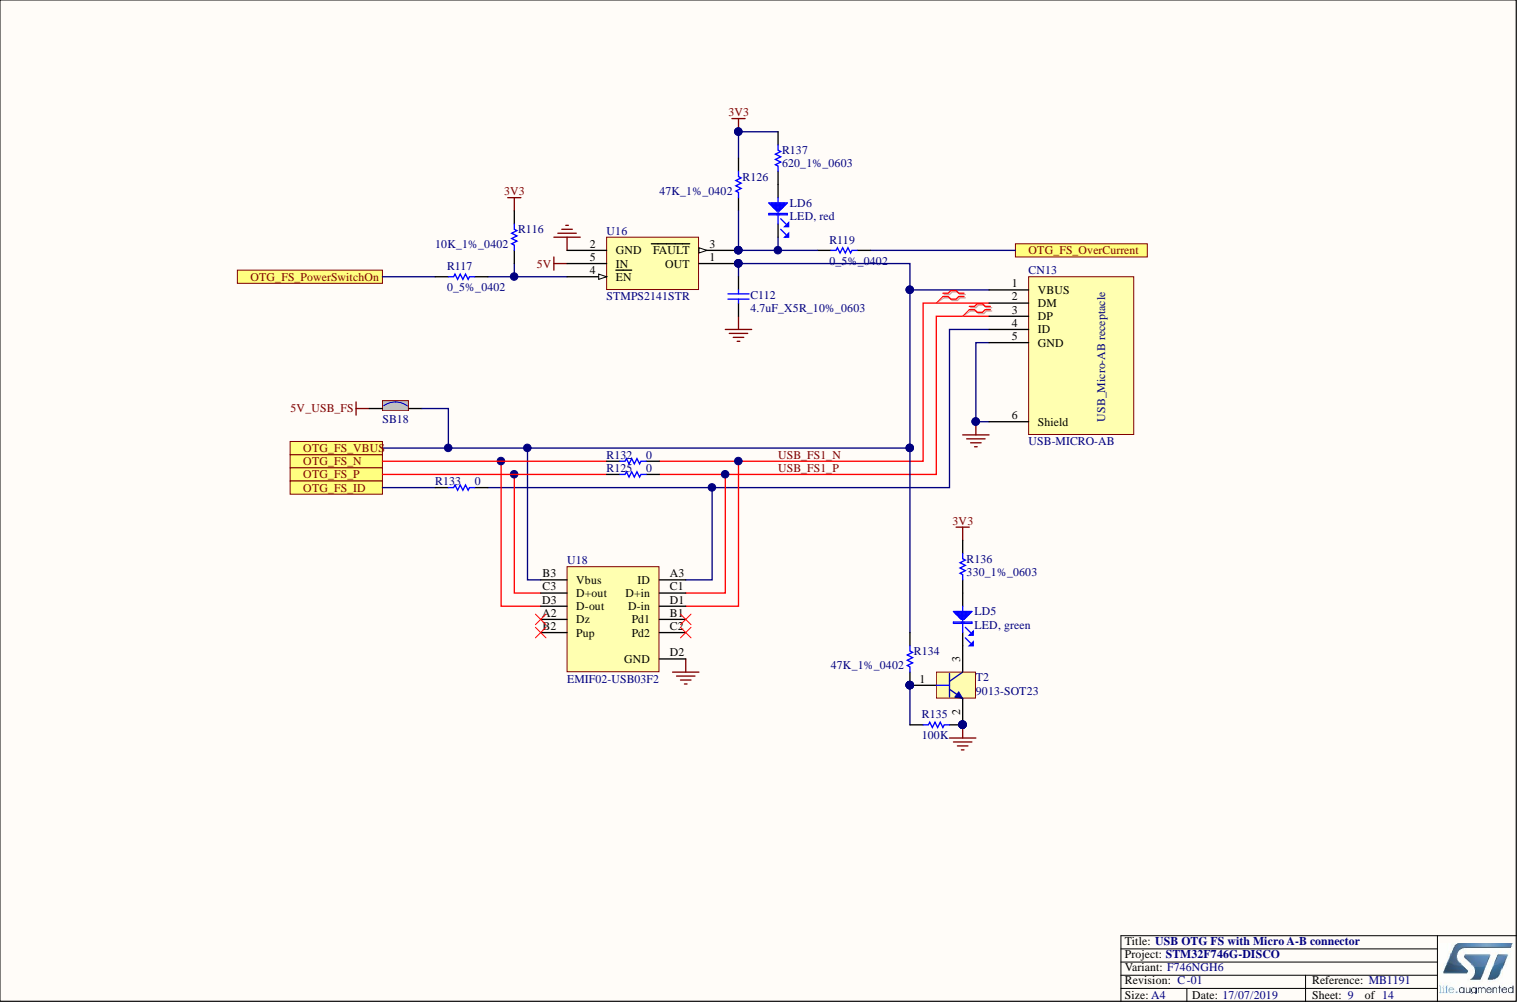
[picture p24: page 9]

STMPS2141STR C112 | | DM 2

Title: USB OTG FS with Micro A-B connector

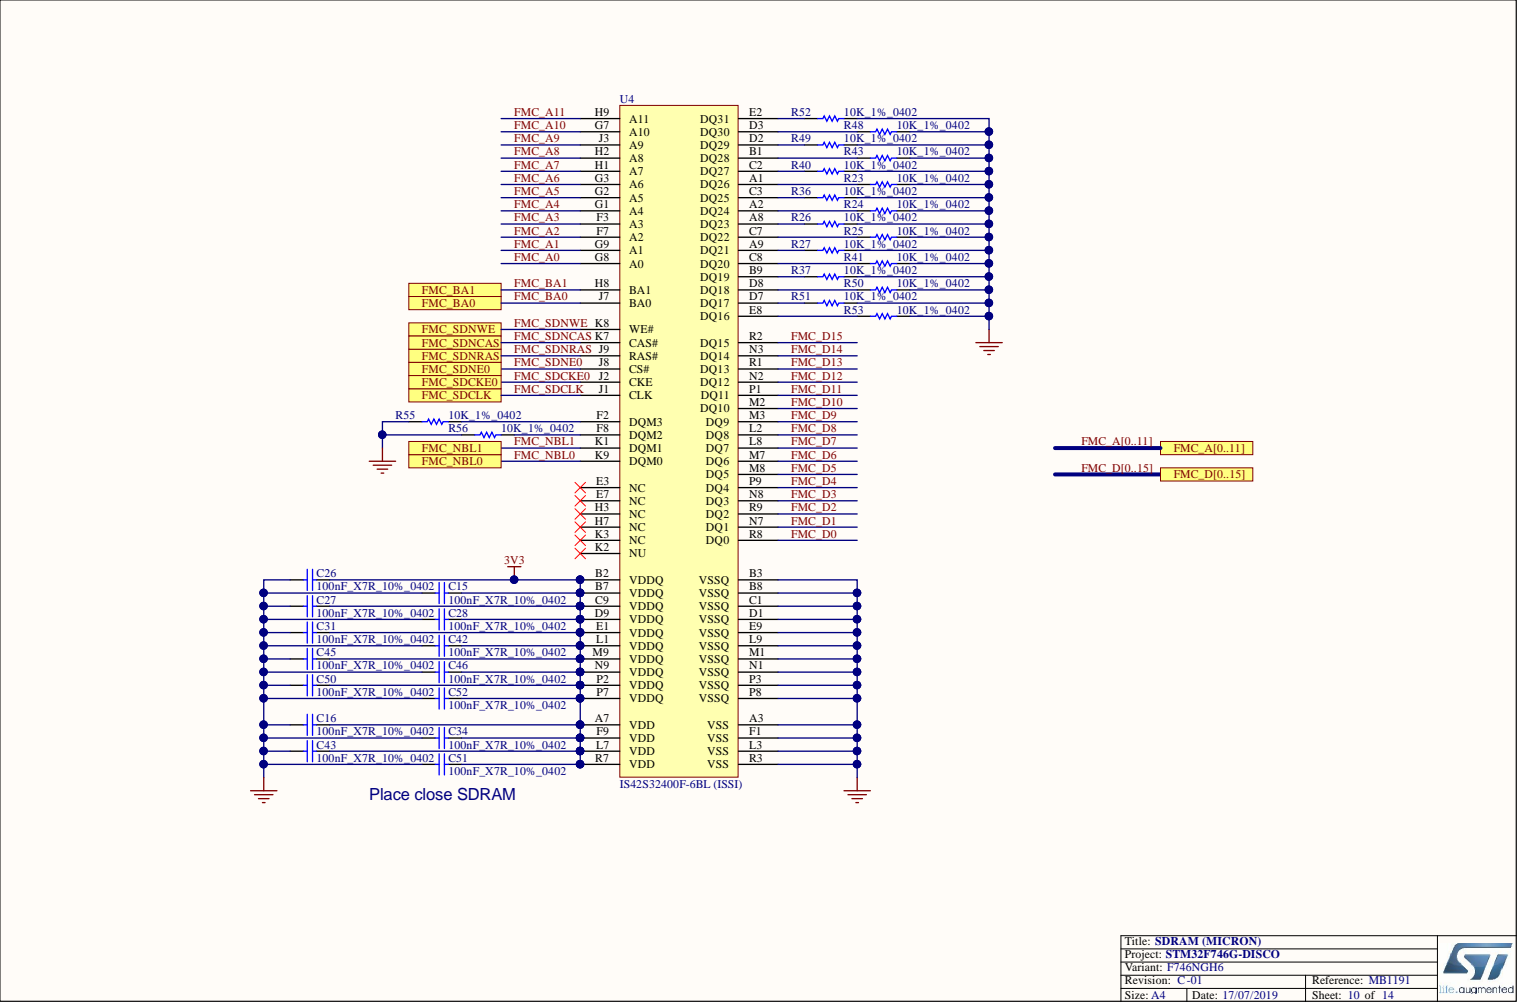
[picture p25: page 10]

1 0 0 nF_ X 7R_ 1 0 % _ 0 4 0 2 | C1 5
C2 7 | 1 0 0 nF_ X 7R_ 1 0 % _ 0 4 0 2
1 0 0 nF_ X 7R_ 1 0 % _ 0 4 0 2 | C2 8 | D 9 | | D 1
C3 1 | 1 0 0 nF_ X 7R_ 1 0 % _ 0 4 0 2 | E 1 | | E 9
1 0 0 nF_ X 7R_ 1 0 % _ 0 4 0 2 | C4 2 | L 1 | | L 9
C4 5 | 1 0 0 nF_ X 7R_ 1 0 % _ 0 4 0 2
1 0 0 nF_ X 7R_ 1 0 % _ 0 4 0 2 | C4 6 | N 9 | | N 1
C5 0 | 1 0 0 nF_ X 7R_ 1 0 % _ 0 4 0 2
1 0 0 nF_ X 7R_ 1 0 % _ 0 4 0 2 | C5 2

1 0 0 nF_ X 7R_ 1 0 % _ 0 4 0 2 | C3 4
C4 3 | 1 0 0 nF_ X 7R_ 1 0 % _ 0 4 0 2 | L 7 | | L 3
1 0 0 nF_ X 7R_ 1 0 % _ 0 4 0 2 | C5 1

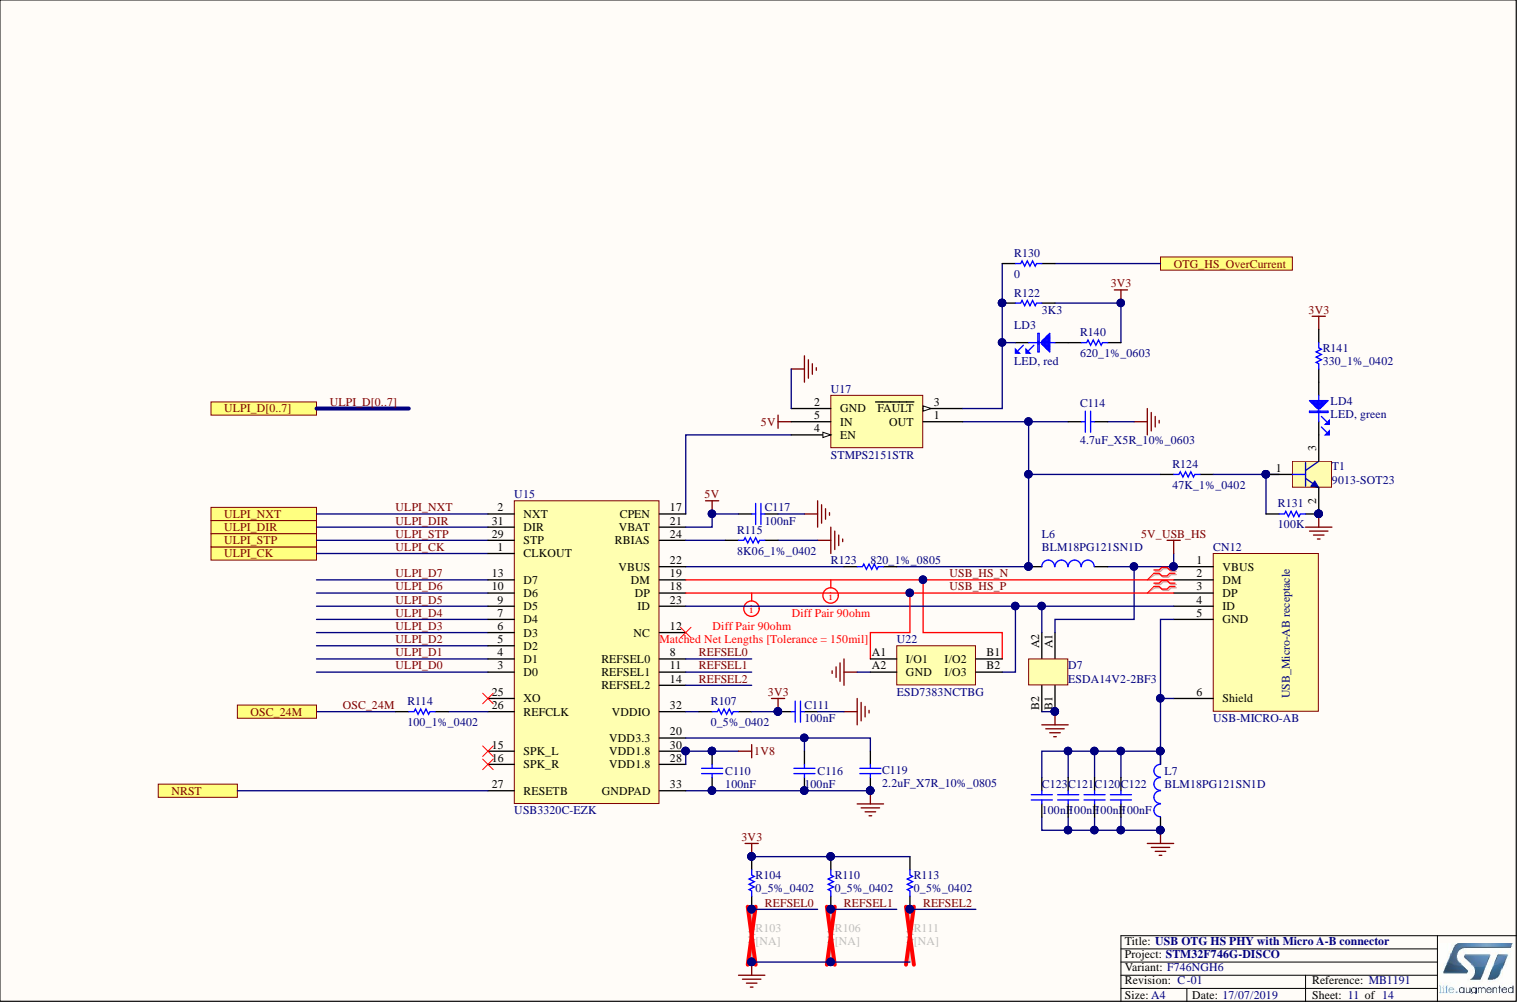
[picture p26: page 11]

D6 10 | USB_HS_P | DP 3
D5 9 | | | ID 4

Matched Net Lengths [Tolerance = 150mil]

Title: USB OTG HS PHY with Micro A-B connector

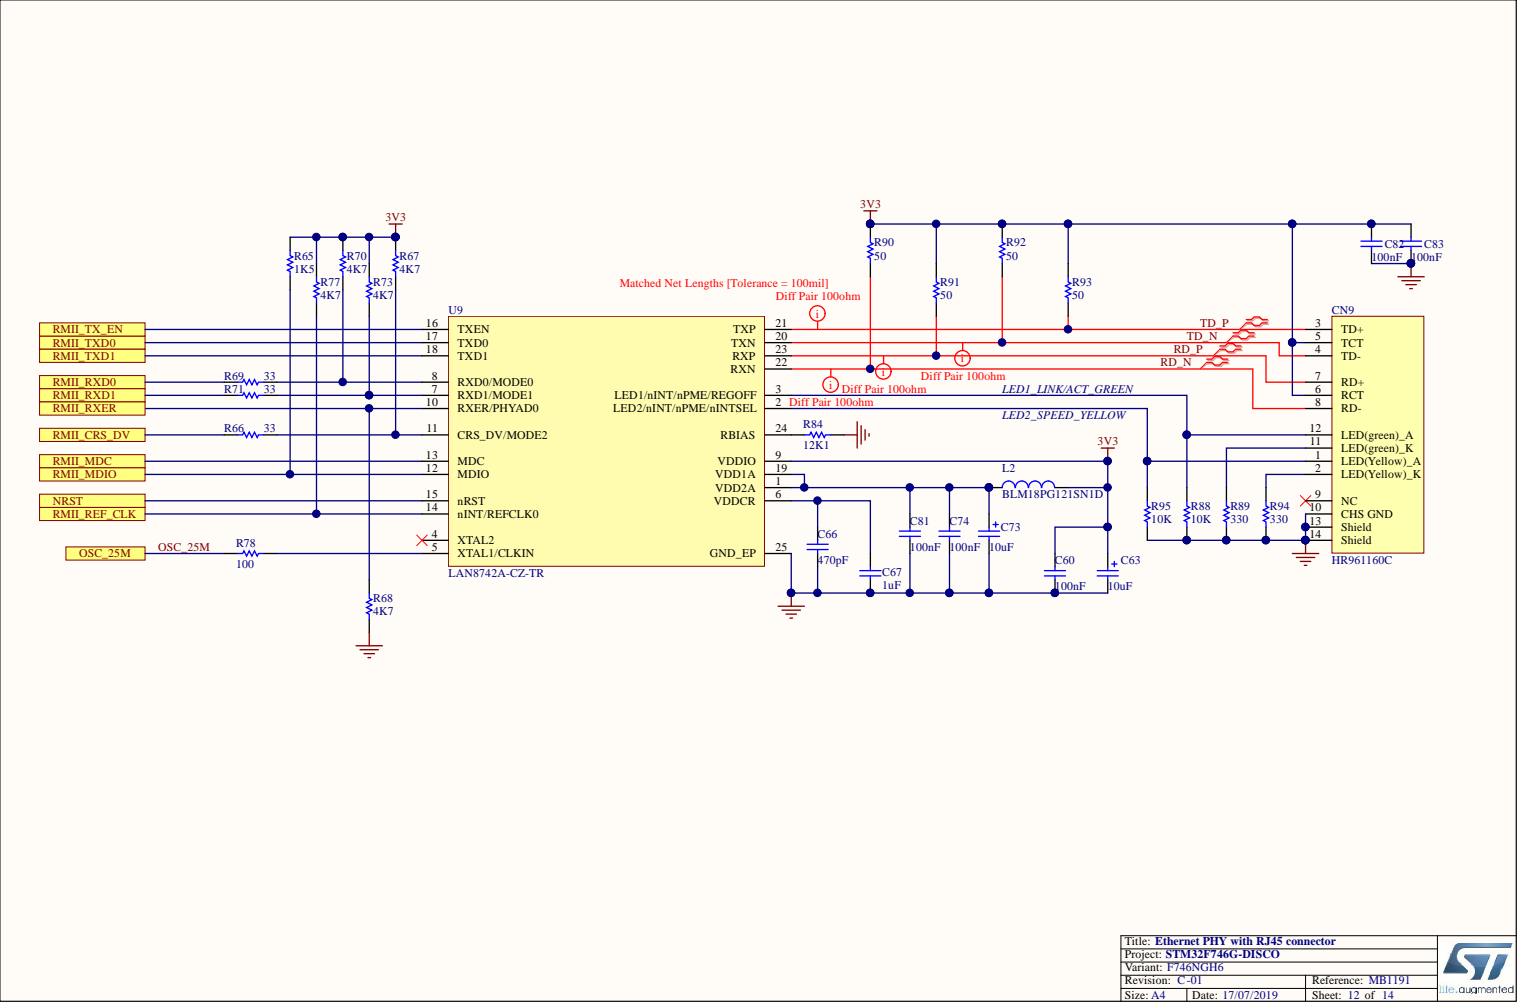
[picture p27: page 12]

1 7 | 2 0 | T D _ N | 5
1 8 | 2 3 | RD _ P | | 4

3 | | i D iff Pair 1 0 0 o h m

i D iff Pair 1 0 0 o h m LED 1 _LINK/ACT_ G R EEN | | 6

2 | D iff Pair 1 0 0 o h m | 8

1 3 | | 2 4 | LED 2 _ S P EED _YELLO W | 1 2

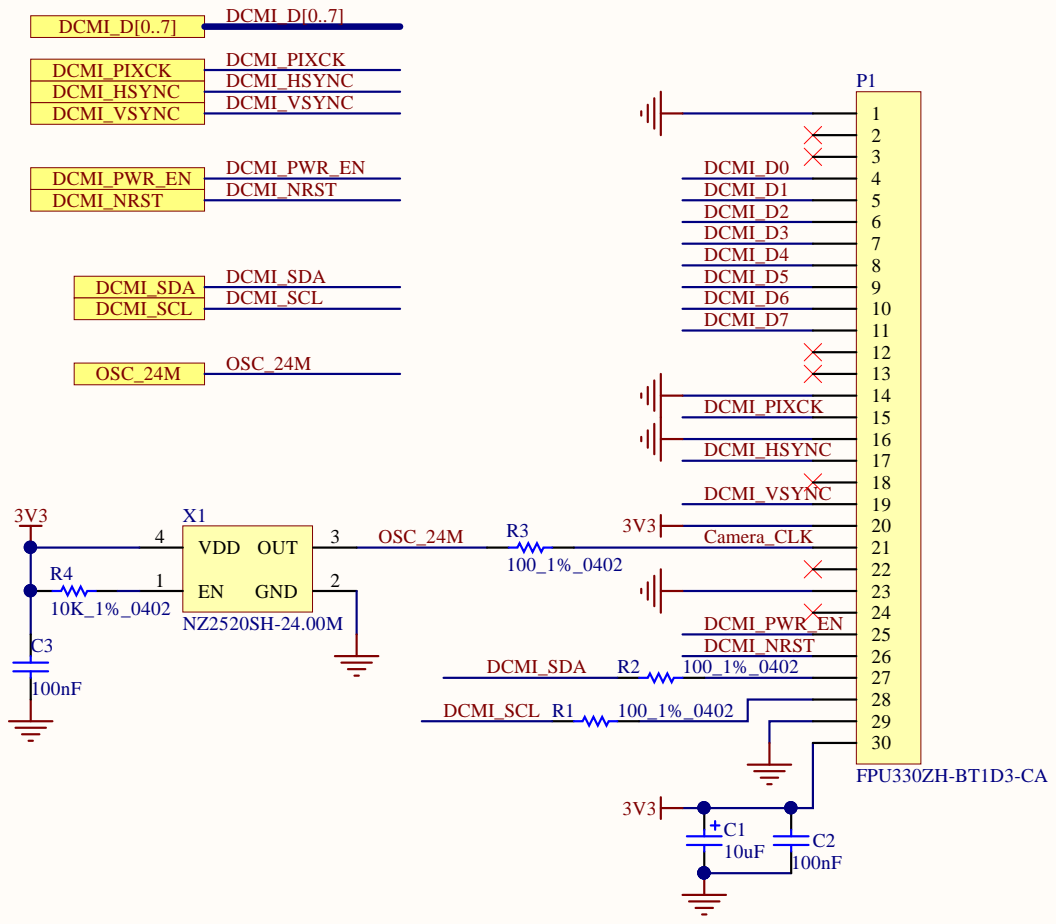
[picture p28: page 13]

Title: External Camera connector


LCD_INT LCD_SCL LCD_SDA LCD_RST | | INT 38 SCL 39 SDA 40 RESET 37

PGND 9 | | 3V3 | VDD 4

Backlight driver & PFC of LCD panel

Title: LCD 4.3" with Capacitive Touch




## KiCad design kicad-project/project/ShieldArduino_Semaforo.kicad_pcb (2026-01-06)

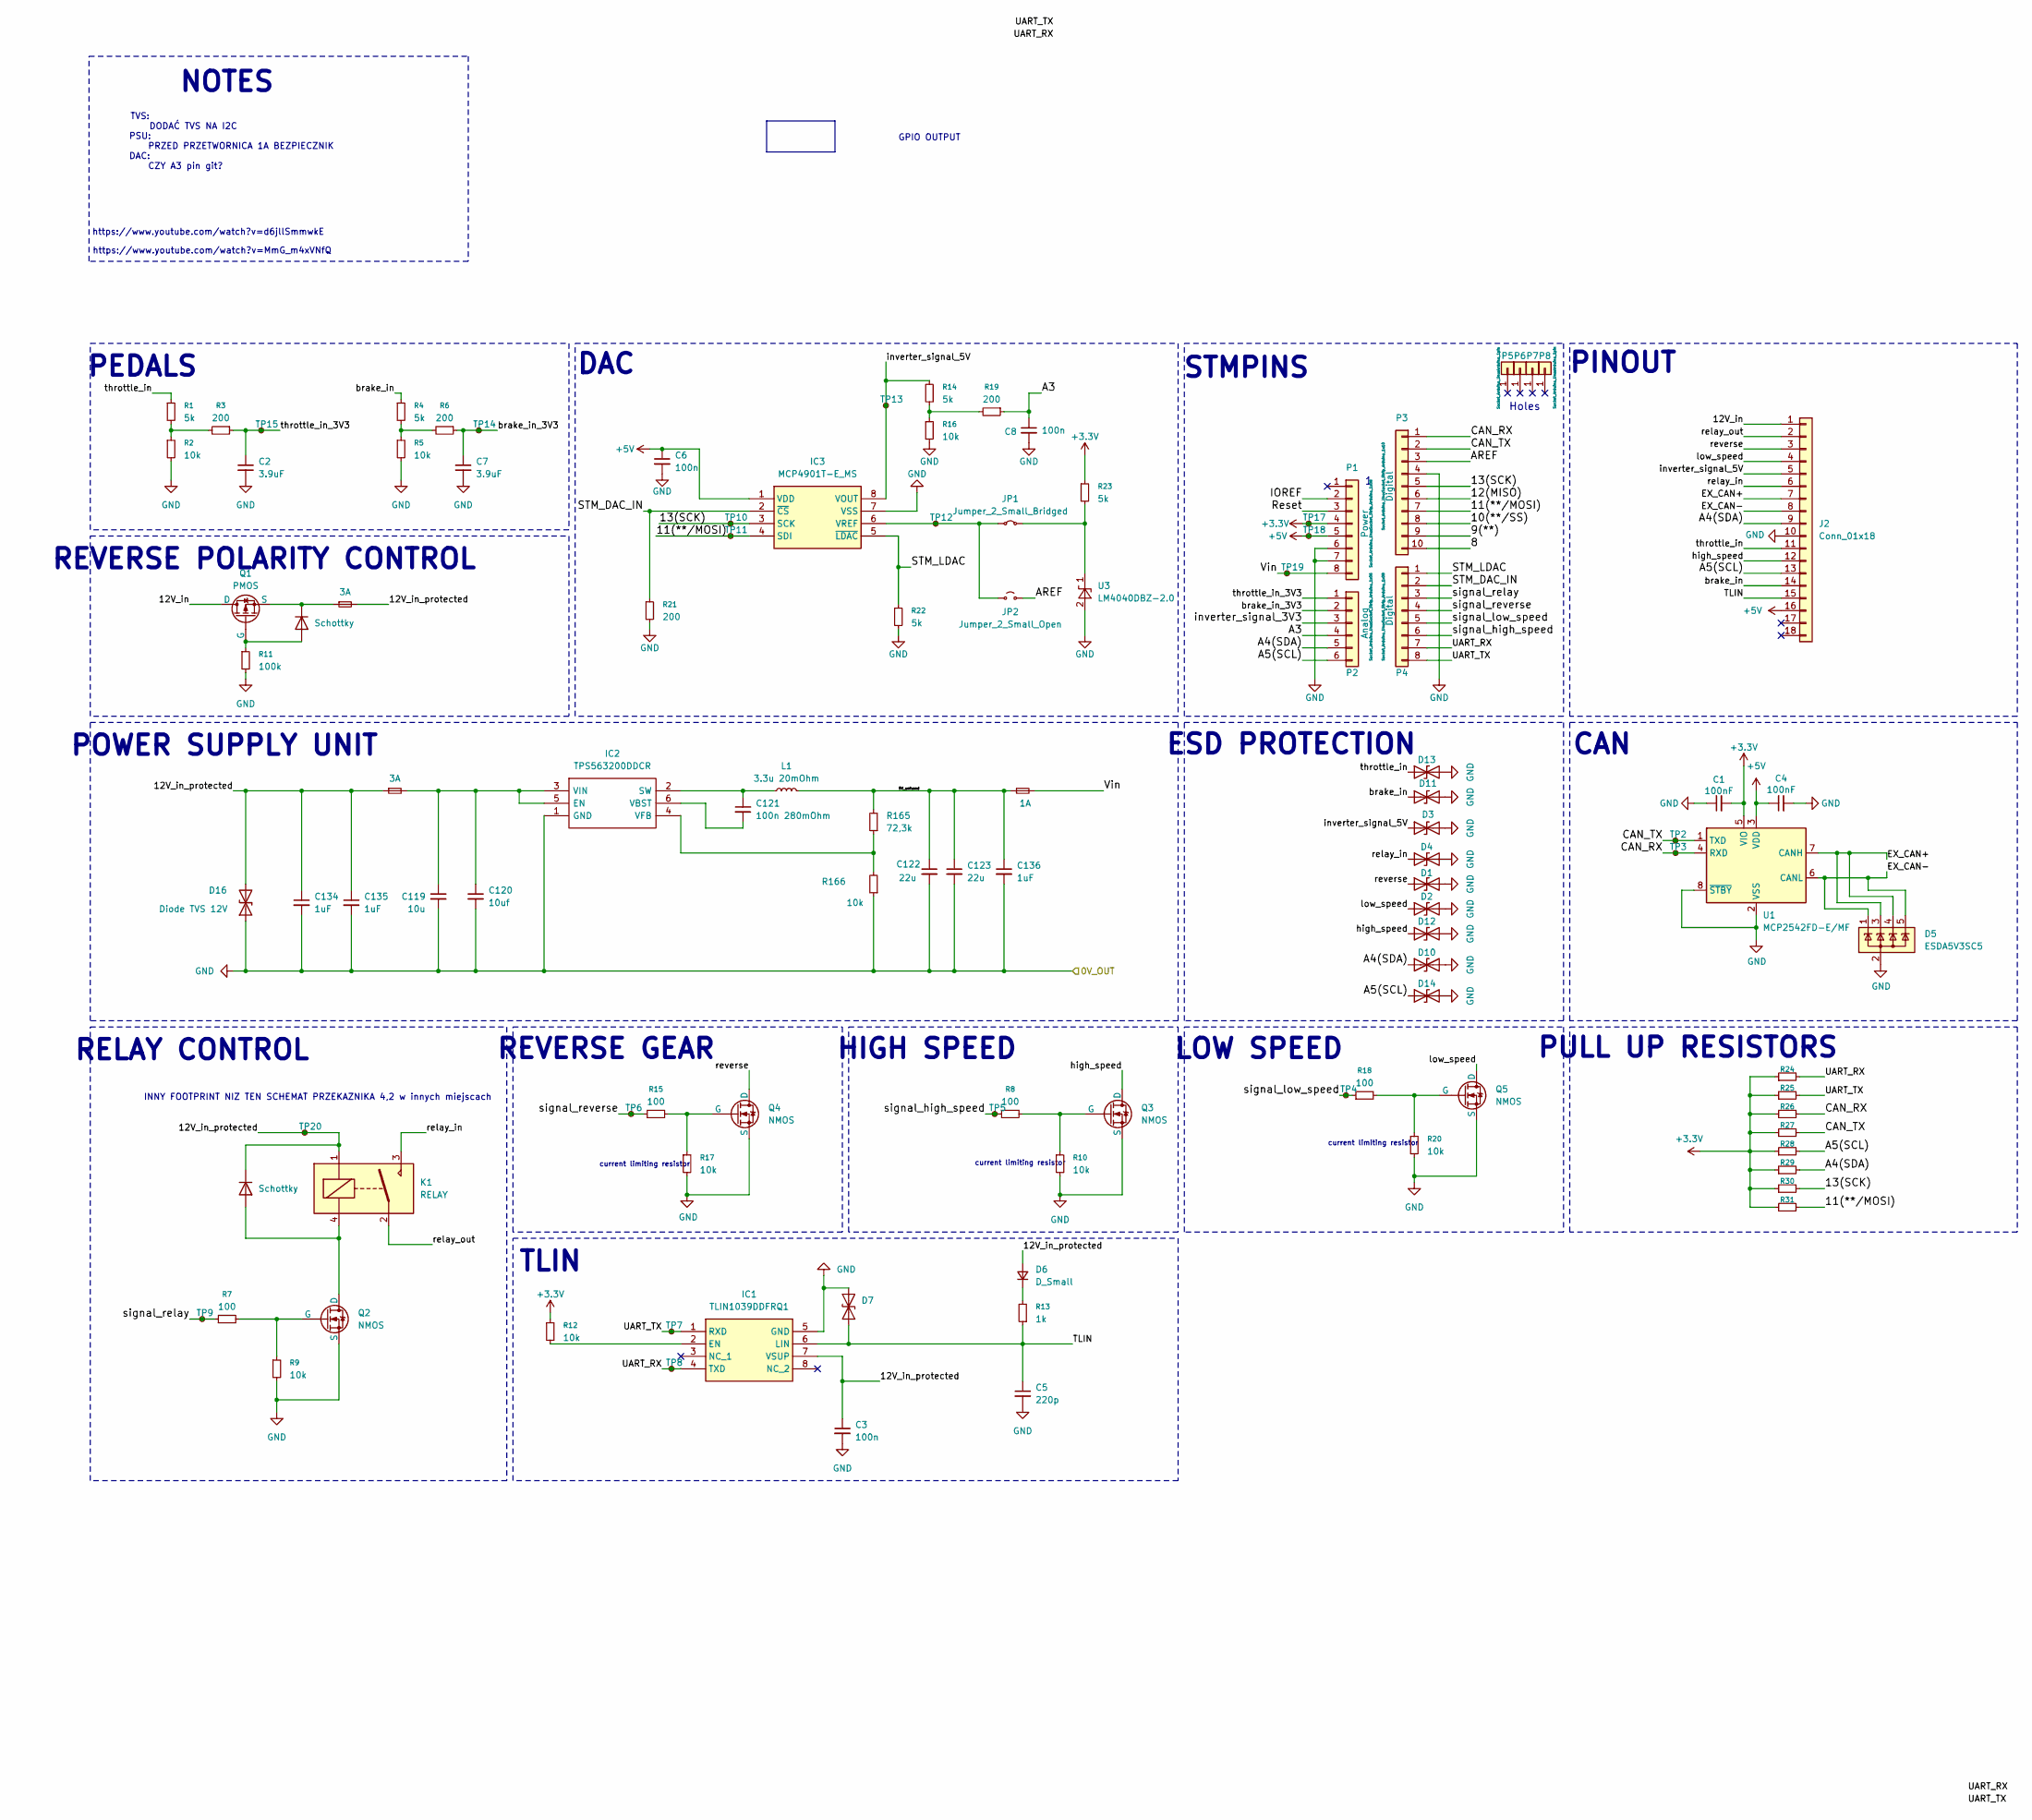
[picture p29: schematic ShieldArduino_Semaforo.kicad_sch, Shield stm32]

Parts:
C1, C4: 100nF; C_0603_1608Metric_Pad1.08x0.95mm_HandSolder; Manufacturer_Part_Number --; Mouser Part Number --
C2, C7: 3.9uF; C_1206_3216Metric_Pad1.33x1.80mm_HandSolder
C3, C6, C8: 100n; C_0805_2012Metric_Pad1.18x1.45mm_HandSolder
C5: 220p; C_0805_2012Metric_Pad1.18x1.45mm_HandSolder
C119: 10u; C_0805_2012Metric_Pad1.18x1.45mm_HandSolder
C120: 10uf; C_0805_2012Metric_Pad1.18x1.45mm_HandSolder
C121: 100n 280mOhm; C_0805_2012Metric_Pad1.18x1.45mm_HandSolder
C122, C123: 22u; C_0603_1608Metric_Pad1.08x0.95mm_HandSolder
C134, C135, C136: 1uF; C_0603_1608Metric_Pad1.08x0.95mm_HandSolder
D1, D2, D3, D4, D10, D11, D12, D13, D14: 6V; D_SOD-123F
D5: ESDA5V3SC5; SOT-23-5
D6: D_Small; SODFL3618X100N
D7: ESD131-B1-W0201; SOD2613X100N
D8, D9: Schottky; D_SOD-123
D16: Diode TVS 12V; D_SOD-323_HandSoldering
F1, F3: 3A; Fuse_0603_1608Metric_Pad1.05x0.95mm_HandSolder
F4: 1A; Fuse_0603_1608Metric_Pad1.05x0.95mm_HandSolder
IC1: TLIN1039DDFRQ1; SOT65P280X110-8N; Mouser Part Number 595-TLIN1039DDFRQ1
IC2: TPS563200DDCR; Mouser Part Number 595-TPS563200DDCR
IC3: MCP4901T-E_MS; SOP65P490X110-8N; Mouser Part Number 579-MCP4901T-E/MS
J2: Conn_01x18; M80-54016YY
JP1: Jumper_2_Small_Bridged; SolderJumper-2_P1.3mm_Bridged_RoundedPad1.0x1.5mm
JP2: Jumper_2_Small_Open; SolderJumper-2_P1.3mm_Open_RoundedPad1.0x1.5mm
K1: RELAY; RE034012
L1: 3.3u 20mOhm; CLF7045__
P1: Power; Socket_Strip_Arduino_1x08
P2: Analog; Socket_Strip_Arduino_1x06
P3: Digital; Socket_Strip_Arduino_1x10
P4: Digital; Socket_Strip_Arduino_1x08
P5, P6, P7, P8: CONN_01X01; Arduino_1pin
Q1: PMOS; SOT-23-3
Q2, Q3, Q4, Q5: NMOS; SOT-23-3
R1, R4, R14, R22, R23: 5k; R_0603_1608Metric_Pad0.98x0.95mm_HandSolder
R2, R5, R16, R166: 10k; R_0603_1608Metric_Pad0.98x0.95mm_HandSolder
R3, R6, R19, R21: 200; R_0603_1608Metric_Pad0.98x0.95mm_HandSolder
R7, R8, R15, R18: 100; R_0805_2012Metric_Pad1.20x1.40mm_HandSolder
R9, R10, R12, R17, R20, R24, R25, R26, R27, R28, R29, R30, R31: 10k; R_0805_2012Metric_Pad1.20x1.40mm_HandSolder
R11: 100k; R_0805_2012Metric_Pad1.20x1.40mm_HandSolder
R13: 1k; R_0805_2012Metric_Pad1.20x1.40mm_HandSolder
R165: 72,3k; R_0603_1608Metric_Pad0.98x0.95mm_HandSolder
TP2, TP3, TP4, TP5, TP6, TP7, TP8, TP9, TP10, TP11, TP12, TP13, TP14, TP15, TP17, TP18, TP19, TP20: TestPoint_Small; TestPoint_Pad_D1.5mm
U1: MCP2542FD-E/MF; SOIC127P600X175-8N; Manufacturer_Part_Number MCP2542FD-E/MF; Mouser Part Number 579-MCP2542FD-E/MF
U3: LM4040DBZ-2.0; SOT-23

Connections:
+3.3V: C1.2, P1.4, R12.1, R23.1, R24.1, R25.1, R26.1, R27.1, R28.1, R29.1, R30.1, R31.1, TP17.1, U1.5 (VIO)
+5V: C4.1, C6.1, IC3.1 (VDD), J2.16, P1.5, TP18.1, U1.3 (VDD)
/5V_unfused: C122.1, C123.1, C136.1, F4.1, L1.2, R165.2
/8: P3.10
/9(**): P3.9
/10(**/SS): P3.8
/11(**/MOSI): IC3.4 (SDI), P3.7, R31.2, TP11.1
/12(MISO): P3.6
/12V_in: J2.1, Q1.1 (D)
/12V_in_protected: C3.1, C134.1, C135.1, D6.2 (A), D8.1 (K), D16.2 (A2), F1.2, F3.1, IC1.7 (VSUP), K1.1, TP20.1
/13(SCK): IC3.3 (SCK), P3.5, R30.2, TP10.1
/ relay_in: D4.1 (A1), J2.6, K1.3
/A3: C8.1, P2.4, R19.1
/A4(SDA): D10.1 (A1), J2.9, P2.5, R29.2
/A5(SCL): D14.1 (A1), J2.13, P2.6, R28.2
/AREF: JP2.2 (B), P3.3
/CAN_RX: P3.1, R26.2, TP3.1, U1.4 (RXD)
/CAN_TX: P3.2, R27.2, TP2.1, U1.1 (TXD)
/EX_CAN+: D5.3 (K), D5.4 (K), J2.7, U1.7 (CANH)
/EX_CAN-: D5.1 (K), D5.5 (K), J2.8, U1.6 (CANL)
/IOREF: P1.2
/Reset: P1.3
/STM_DAC_IN: IC3.2 (~CS), P4.2, R21.1
/STM_LDAC: IC3.5 (~LDAC), P4.1, R22.1
/TLIN: C5.1, D7.1 (A1), IC1.6 (LIN), J2.15, R13.1
/UART_RX: IC1.4 (TXD), P4.7, R24.2, TP8.1
/UART_TX: IC1.1 (RXD), P4.8, R25.2, TP7.1
/Vin: F4.2, P1.8, TP19.1
/brake_in: D11.1 (A1), J2.14, R4.1
/brake_in_3V3: C7.1, P2.2, R6.1, TP14.1
/high_speed: D12.1 (A1), J2.12, Q3.1 (D)
/inverter_signal_3V3: P2.3
/inverter_signal_5V: D3.1 (A1), IC3.8 (VOUT), J2.5, R14.1, TP13.1
/low_speed: D2.1 (A1), J2.4, Q5.1 (D)
/relay_out: J2.2, K1.2
/reverse: D1.1 (A1), J2.3, Q4.1 (D)
/signal_high_speed: P4.6, R8.1, TP5.1
/signal_low_speed: P4.5, R18.1, TP4.1
/signal_relay: P4.3, R7.1, TP9.1
/signal_reverse: P4.4, R15.1, TP6.1
/throttle_in: D13.1 (A1), J2.11, R1.1
/throttle_in_3V3: C2.1, P2.1, R3.1, TP15.1
GND: C1.1, C2.2, C3.2, C4.2, C5.2, C6.2, C7.2, C8.2, C119.2, C120.2, C122.2, C123.2, C134.2, C135.2, C136.2, D1.2 (A2), D2.2 (A2), D3.2 (A2), D4.2 (A2), D5.2 (A), D7.2 (A2), D10.2 (A2), D11.2 (A2), D12.2 (A2), D13.2 (A2), D14.2 (A2), D16.1 (A1), IC1.5 (GND), IC2.1 (GND), IC3.7 (VSS), J2.10, P1.6, P1.7, P3.4, Q2.3 (S), Q3.3 (S), Q4.3 (S), Q5.3 (S), R2.2, R5.2, R9.2, R10.2, R11.2, R16.2, R17.2, R20.2, R21.2, R22.2, R166.1, U1.2 (VSS), U1.8 (~STBY), U1.9 (VSS), U3.2 (A)
unnamed: D6.1 (K), R13.2
unnamed: D8.2 (A), K1.4, Q2.1 (D)
unnamed: D9.2 (A), Q1.2 (G), R11.1
unnamed: D9.1 (K), F1.1, Q1.3 (S)
unnamed: IC1.2 (EN), R12.2
unnamed: C119.1, C120.1, F3.2, IC2.3 (VIN), IC2.5 (EN)
unnamed: C121.1, IC2.2 (SW), L1.1
unnamed: C121.2, IC2.6 (VBST)
unnamed: IC2.4 (VFB), R165.1, R166.2
unnamed: IC3.6 (VREF), JP1.1 (A), JP2.1 (A), TP12.1
unnamed: JP1.2 (B), R23.2, U3.1 (K)
unnamed: Q2.2 (G), R7.2, R9.1
unnamed: Q3.2 (G), R8.2, R10.1
unnamed: Q4.2 (G), R15.2, R17.1
unnamed: Q5.2 (G), R18.2, R20.1
unnamed: R1.2, R2.1, R3.2
unnamed: R4.2, R5.1, R6.2
unnamed: R14.2, R16.1, R19.2

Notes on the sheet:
PSU: PRZED PRZETWORNICA 1A BEZPIECZNIK DAC: CZY A3 pin git?
DAC
current limiting resistor
ESD PROTECTION
TLIN
POWER SUPPLY UNIT
Holes
LOW SPEED
REVERSE POLARITY CONTROL
https://www.youtube.com/watch?v=d6jllSmmwkE
TVS: DODAĆ TVS NA I2C
REVERSE GEAR
NOTES
GPIO OUTPUT
CAN
PEDALS
PULL UP RESISTORS
HIGH SPEED
PINOUT
RELAY CONTROL
https://www.youtube.com/watch?v=MmG_m4xVNfQ
INNY FOOTPRINT NIZ TEN SCHEMAT PRZEKAZNIKA 4,2 w innych miejscach
STMPINS

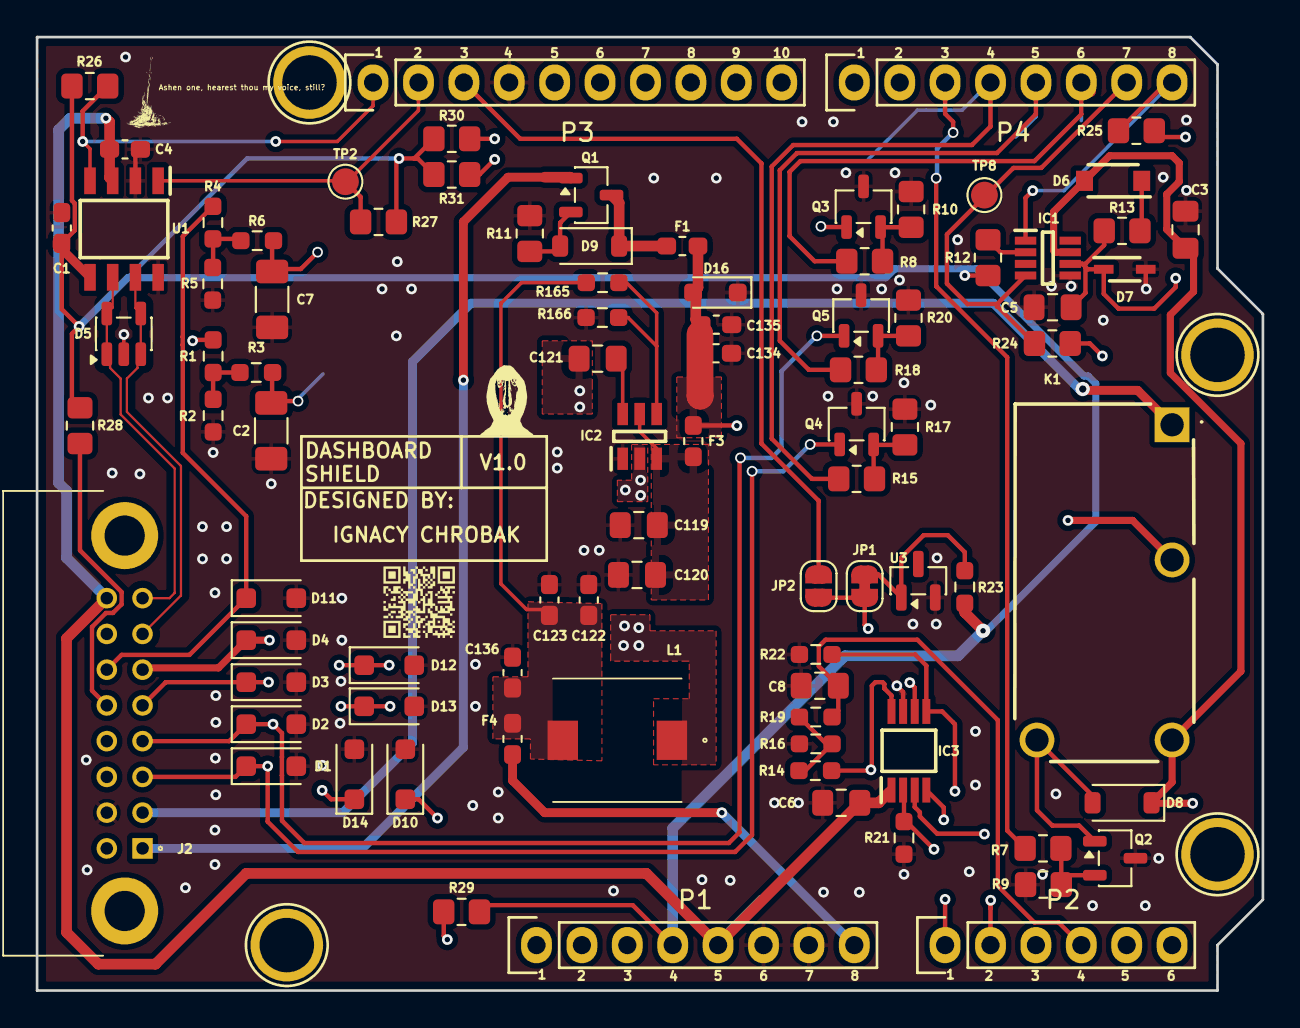
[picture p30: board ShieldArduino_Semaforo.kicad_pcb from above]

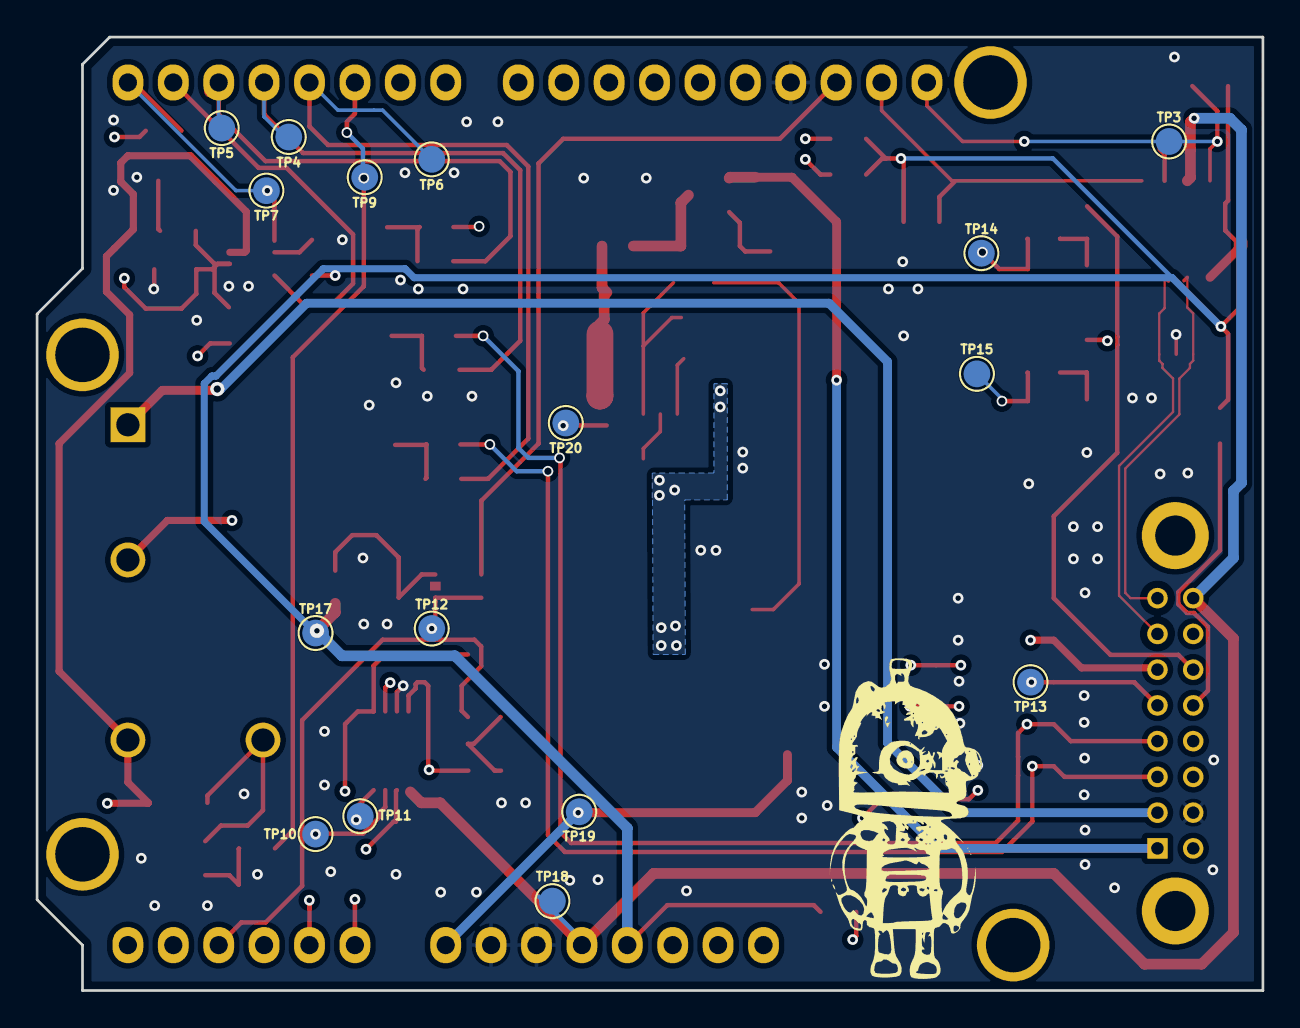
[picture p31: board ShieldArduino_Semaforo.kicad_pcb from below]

Board: 4 copper layers, 68.6 x 53.3 mm, 108 parts (16 on the bottom side), 54 nets.

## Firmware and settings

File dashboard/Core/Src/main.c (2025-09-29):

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
/* Includes ------------------------------------------------------------------*/
#include "main.h"
#include "cmsis_os.h"
#include "libjpeg.h"
#include "app_touchgfx.h"

/* USER CODE BEGIN PD */

#define REFRESH_COUNT        1835

#define SDRAM_TIMEOUT                            ((uint32_t)0xFFFF)
#define SDRAM_MODEREG_BURST_LENGTH_1             ((uint16_t)0x0000)
#define SDRAM_MODEREG_BURST_LENGTH_2             ((uint16_t)0x0001)
#define SDRAM_MODEREG_BURST_LENGTH_4             ((uint16_t)0x0002)
#define SDRAM_MODEREG_BURST_LENGTH_8             ((uint16_t)0x0004)
#define SDRAM_MODEREG_BURST_TYPE_SEQUENTIAL      ((uint16_t)0x0000)
#define SDRAM_MODEREG_BURST_TYPE_INTERLEAVED     ((uint16_t)0x0008)
#define SDRAM_MODEREG_CAS_LATENCY_2              ((uint16_t)0x0020)
#define SDRAM_MODEREG_CAS_LATENCY_3              ((uint16_t)0x0030)
#define SDRAM_MODEREG_OPERATING_MODE_STANDARD    ((uint16_t)0x0000)
#define SDRAM_MODEREG_WRITEBURST_MODE_PROGRAMMED ((uint16_t)0x0000)
#define SDRAM_MODEREG_WRITEBURST_MODE_SINGLE     ((uint16_t)0x0200)

#define FLASH_READ_JEDEC_ID				0x9F
#define FLASH_FAST_READ_QUAD_IO		 	0xEB
#define FLASH_REVC03_MANUFACTURER_ID	0xEF
#define FLASH_N25Q128A_DUMMY_CYCLES		0x0A
#define FLASH_W25Q128J_DUMMY_CYCLES		0x06

/* USER CODE END PD */


CRC_HandleTypeDef hcrc;

DMA2D_HandleTypeDef hdma2d;

I2C_HandleTypeDef hi2c3;

LTDC_HandleTypeDef hltdc;

QSPI_HandleTypeDef hqspi;

SDRAM_HandleTypeDef hsdram1;

/* Definitions for defaultTask */
osThreadId_t defaultTaskHandle;
const osThreadAttr_t defaultTask_attributes = {
  .name = "defaultTask",
  .stack_size = 128 * 4,
  .priority = (osPriority_t) osPriorityNormal,
};
/* Definitions for TouchGFXTask */
osThreadId_t TouchGFXTaskHandle;
const osThreadAttr_t TouchGFXTask_attributes = {
  .name = "TouchGFXTask",
  .stack_size = 4096 * 4,
  .priority = (osPriority_t) osPriorityNormal,
};
/* Definitions for videoTask */
osThreadId_t videoTaskHandle;
const osThreadAttr_t videoTask_attributes = {
  .name = "videoTask",
  .stack_size = 1000 * 4,
  .priority = (osPriority_t) osPriorityLow,
};
/* USER CODE BEGIN PV */
static FMC_SDRAM_CommandTypeDef Command;
/* USER CODE END PV */

void SystemClock_Config(void);
static void MPU_Config(void);
static void MX_GPIO_Init(void);
static void MX_CRC_Init(void);
static void MX_DMA2D_Init(void);
static void MX_FMC_Init(void);
static void MX_I2C3_Init(void);
static void MX_LTDC_Init(void);
static void MX_QUADSPI_Init(void);
void StartDefaultTask(void *argument);
extern void TouchGFX_Task(void *argument);
extern void videoTaskFunc(void *argument);

/* USER CODE BEGIN PFP */
void GetManufacturerId (uint8_t *manufacturer_id);
void EnableMemoryMappedMode(uint8_t manufacturer_id);  

/* USER CODE END PFP */

/**
  * @brief  The application entry point.
  * @retval int
  */
int main(void)
{

  /* MPU Configuration--------------------------------------------------------*/
  MPU_Config();

  /* Enable the CPU Cache */

  /* Enable I-Cache---------------------------------------------------------*/
  SCB_EnableICache();

  /* Enable D-Cache---------------------------------------------------------*/
  SCB_EnableDCache();

  /* MCU Configuration--------------------------------------------------------*/

  /* Reset of all peripherals, Initializes the Flash interface and the Systick. */
  HAL_Init();

  /* Configure the system clock */
  SystemClock_Config();

  /* Initialize all configured peripherals */
  MX_GPIO_Init();
  MX_CRC_Init();
  MX_DMA2D_Init();
  MX_FMC_Init();
  MX_I2C3_Init();
  MX_LTDC_Init();
  MX_QUADSPI_Init();
  MX_LIBJPEG_Init();
  MX_TouchGFX_Init();
  /* Call PreOsInit function */
  MX_TouchGFX_PreOSInit();
  /* Init scheduler */
  osKernelInitialize();

  /* USER CODE BEGIN RTOS_MUTEX */
  /* add mutexes, ... */
  /* USER CODE END RTOS_MUTEX */

  /* USER CODE BEGIN RTOS_SEMAPHORES */
  /* add semaphores, ... */
  /* USER CODE END RTOS_SEMAPHORES */

  /* USER CODE BEGIN RTOS_TIMERS */
  /* start timers, add new ones, ... */
  /* USER CODE END RTOS_TIMERS */

  /* USER CODE BEGIN RTOS_QUEUES */
  /* add queues, ... */
  /* USER CODE END RTOS_QUEUES */

  /* Create the thread(s) */
  /* creation of defaultTask */
  defaultTaskHandle = osThreadNew(StartDefaultTask, NULL, &defaultTask_attributes);

  /* creation of TouchGFXTask */
  TouchGFXTaskHandle = osThreadNew(TouchGFX_Task, NULL, &TouchGFXTask_attributes);

  /* creation of videoTask */
  videoTaskHandle = osThreadNew(videoTaskFunc, NULL, &videoTask_attributes);

  /* USER CODE BEGIN RTOS_THREADS */
  /* add threads, ... */
  /* USER CODE END RTOS_THREADS */

  /* USER CODE BEGIN RTOS_EVENTS */
  /* add events, ... */
  /* USER CODE END RTOS_EVENTS */

  /* Start scheduler */
  osKernelStart();

  /* We should never get here as control is now taken by the scheduler */

  /* Infinite loop */
  /* USER CODE BEGIN WHILE */
  while (1)
  {
    /* USER CODE END WHILE */

    /* USER CODE BEGIN 3 */
  }
  /* USER CODE END 3 */
}

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
/* USER CODE BEGIN 4 */

// Read manufacturer ID of external QSPI flash
void GetManufacturerId (uint8_t *manufacturer_id)
{
  QSPI_CommandTypeDef s_command_id;

  /* Initialize the read flag status register command */
  s_command_id.InstructionMode   = QSPI_INSTRUCTION_1_LINE;
  s_command_id.Instruction       = FLASH_READ_JEDEC_ID;
  s_command_id.AddressMode       = QSPI_ADDRESS_NONE;
  s_command_id.AlternateByteMode = QSPI_ALTERNATE_BYTES_NONE;
  s_command_id.DataMode          = QSPI_DATA_1_LINE;
  s_command_id.DummyCycles       = 0;
  s_command_id.NbData            = 1;
  s_command_id.DdrMode           = QSPI_DDR_MODE_DISABLE;
  s_command_id.DdrHoldHalfCycle  = QSPI_DDR_HHC_ANALOG_DELAY;
  s_command_id.SIOOMode          = QSPI_SIOO_INST_EVERY_CMD;

  /* Configure the command */
  if (HAL_QSPI_Command(&hqspi, &s_command_id, HAL_QPSI_TIMEOUT_DEFAULT_VALUE) != HAL_OK)
  {
	  Error_Handler();
  }

  /* Reception of the data */
  if (HAL_QSPI_Receive(&hqspi, manufacturer_id, HAL_QPSI_TIMEOUT_DEFAULT_VALUE) != HAL_OK)
  {
	  Error_Handler();
  }
}

// Enable memory mapped mode for external QSPI flash
void EnableMemoryMappedMode(uint8_t manufacturer_id)  
{
  QSPI_CommandTypeDef      s_command;
  QSPI_MemoryMappedTypeDef s_mem_mapped_cfg;

  /* Configure the command for the read instruction */
  s_command.InstructionMode   = QSPI_INSTRUCTION_1_LINE;
  s_command.Instruction       = FLASH_FAST_READ_QUAD_IO;
  s_command.AddressMode       = QSPI_ADDRESS_4_LINES;
  s_command.AddressSize       = QSPI_ADDRESS_24_BITS;
  s_command.AlternateByteMode = QSPI_ALTERNATE_BYTES_NONE;
  s_command.DataMode          = QSPI_DATA_4_LINES;
  
  // Set dummy cycles according to manufacturer ID
  s_command.DummyCycles       = manufacturer_id == FLASH_REVC03_MANUFACTURER_ID ? FLASH_W25Q128J_DUMMY_CYCLES : FLASH_N25Q128A_DUMMY_CYCLES;

  s_command.DdrMode           = QSPI_DDR_MODE_DISABLE;
  s_command.DdrHoldHalfCycle  = QSPI_DDR_HHC_ANALOG_DELAY;
  s_command.SIOOMode          = QSPI_SIOO_INST_EVERY_CMD;
  
  /* Configure the memory mapped mode */
  s_mem_mapped_cfg.TimeOutActivation = QSPI_TIMEOUT_COUNTER_DISABLE;
  s_mem_mapped_cfg.TimeOutPeriod     = 0;
  
  if (HAL_QSPI_MemoryMapped(&hqspi, &s_command, &s_mem_mapped_cfg) != HAL_OK)
  {
    Error_Handler();
  }
}

/* USER CODE END 4 */

/* USER CODE BEGIN Header_StartDefaultTask */
/**
  * @brief  Function implementing the defaultTask thread.
  * @param  argument: Not used
  * @retval None
  */
/* USER CODE END Header_StartDefaultTask */
void StartDefaultTask(void *argument)
{
  /* USER CODE BEGIN 5 */
  /* Infinite loop */
  for(;;)
  {
    osDelay(100);
  }
  /* USER CODE END 5 */
}

 /* MPU Configuration */

void MPU_Config(void)
{
  MPU_Region_InitTypeDef MPU_InitStruct = {0};

  /* Disables the MPU */
  HAL_MPU_Disable();

  /** Initializes and configures the Region and the memory to be protected
  */
  MPU_InitStruct.Enable = MPU_REGION_ENABLE;
  MPU_InitStruct.Number = MPU_REGION_NUMBER0;
  MPU_InitStruct.BaseAddress = 0x90000000;
  MPU_InitStruct.Size = MPU_REGION_SIZE_256MB;
  MPU_InitStruct.SubRegionDisable = 0x0;
  MPU_InitStruct.TypeExtField = MPU_TEX_LEVEL0;
  MPU_InitStruct.AccessPermission = MPU_REGION_FULL_ACCESS;
  MPU_InitStruct.DisableExec = MPU_INSTRUCTION_ACCESS_ENABLE;
  MPU_InitStruct.IsShareable = MPU_ACCESS_NOT_SHAREABLE;
  MPU_InitStruct.IsCacheable = MPU_ACCESS_NOT_CACHEABLE;
  MPU_InitStruct.IsBufferable = MPU_ACCESS_NOT_BUFFERABLE;

  HAL_MPU_ConfigRegion(&MPU_InitStruct);

  /** Initializes and configures the Region and the memory to be protected
  */
  MPU_InitStruct.Number = MPU_REGION_NUMBER1;
  MPU_InitStruct.Size = MPU_REGION_SIZE_16MB;
  MPU_InitStruct.IsCacheable = MPU_ACCESS_CACHEABLE;

  HAL_MPU_ConfigRegion(&MPU_InitStruct);
  /* Enables the MPU */
  HAL_MPU_Enable(MPU_PRIVILEGED_DEFAULT);

}

/**
  * @brief  Period elapsed callback in non blocking mode
  * @note   This function is called  when TIM6 interrupt took place, inside
  * HAL_TIM_IRQHandler(). It makes a direct call to HAL_IncTick() to increment
  * a global variable "uwTick" used as application time base.
  * @param  htim : TIM handle
  * @retval None
  */
void HAL_TIM_PeriodElapsedCallback(TIM_HandleTypeDef *htim)
{
  if (htim->Instance == TIM6)
  {
    HAL_IncTick();
  }
}

/**
  * @brief  This function is executed in case of error occurrence.
  * @retval None
  */
void Error_Handler(void)
{
  /* USER CODE BEGIN Error_Handler_Debug */
  /* User can add his own implementation to report the HAL error return state */

  /* USER CODE END Error_Handler_Debug */
}
#ifdef USE_FULL_ASSERT
/**
  * @brief  Reports the name of the source file and the source line number
  *         where the assert_param error has occurred.
  * @param  file: pointer to the source file name
  * @param  line: assert_param error line source number
  * @retval None
  */
void assert_failed(uint8_t *file, uint32_t line)
{
  /* USER CODE BEGIN 6 */
  /* User can add his own implementation to report the file name and line number,
     tex: printf("Wrong parameters value: file %s on line %d\r\n", file, line) */
  /* USER CODE END 6 */
}
#endif /* USE_FULL_ASSERT */

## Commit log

2025-10-23 reamde-fix
    Removed Motor Driver Status from the feature list.
2025-11-19 Dodano test pointy na kazdym sensownym do pomiaru miejscu, dodano przelotki do masy - ground stitching
    [ShieldArduino_Semaforo.kicad_pcb, ShieldArduino_Semaforo.kicad_sch]
2025-12-01 readme-3d/schematic addition
    [ACGRTS4002-HF.stp, CLF7045NIT-3R3N-D.stp, ESD1LIN24DYFR.stp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]
2025-12-01 Include KiCad schematic and 3D model previews in README
    Added previews for KiCad schematic and 3D model.
2025-12-15 freecad-added measurement stls and mounting plate work
    [dashboard-mouting_plate-bottom.FCStd, dashboard-mouting_plate-top.FCStd, measurment_bottom.FCStd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]
2026-01-06 Replace KiCad schematic and 3D model images
    Updated images for KiCad schematic and 3D model previews in the README.
2026-01-13 added gear selector
2026-01-13 updating the temperature table screen
2026-01-13 temperature table screen updated
2026-01-17 Shield by Tadeusz Zakola
    [ShieldArduino_Semaforo.step, dash.SLDASM, przod.SLDPRT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]
2026-01-18 Add IRL pictures section to README
    Added a section for IRL pictures of the STM32 dashboard and shield.
2026-01-18 .zip error fix
    [ShieldArduino_Semaforo.step, dash.SLDASM, dashboard-mouting_plate-bottom.FCStd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]

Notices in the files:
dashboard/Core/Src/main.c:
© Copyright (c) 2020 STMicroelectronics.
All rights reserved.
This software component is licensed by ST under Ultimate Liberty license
